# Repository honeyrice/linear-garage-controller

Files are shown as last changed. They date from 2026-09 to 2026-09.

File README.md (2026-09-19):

# Linear Garage Controller

[English](#english) | [简体中文](#简体中文)

## English

ESP32 + ESPHome retrofit for a **Linear LDCO800** garage opener: encoder-based motion and estimated position, feedback-driven Open/Close control, Home Assistant integration, and Bluetooth Proxy.

**Completed: 2026-09-18.** The original opener, motor, remotes, wall button, and factory protections are retained. The module reads the factory encoder and simulates button presses through a relay. The ESP32 locally translates Open / Close intentions into button sequences driven by feedback.

### Project photos

| Opener model | Factory logic board |
|---|---|
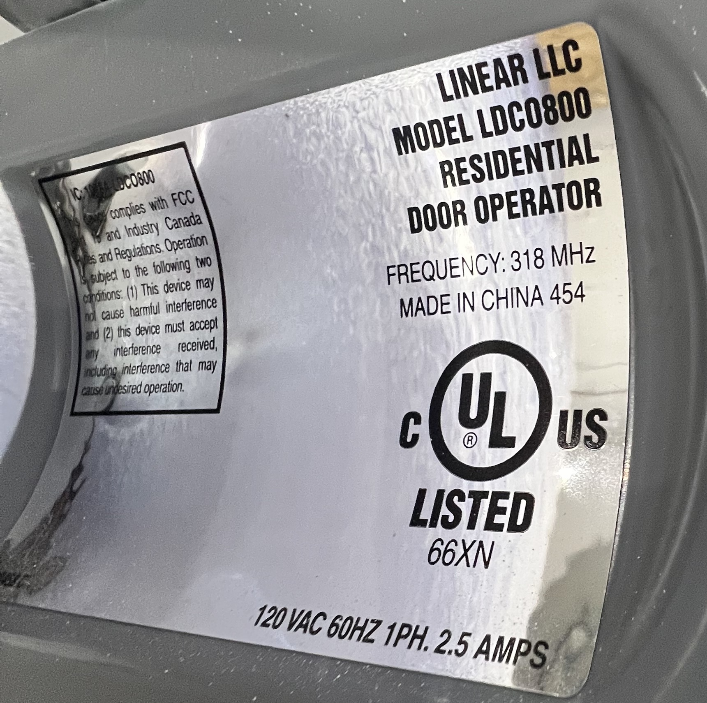
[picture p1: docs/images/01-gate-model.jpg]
Linear LDCO800 model nameplate
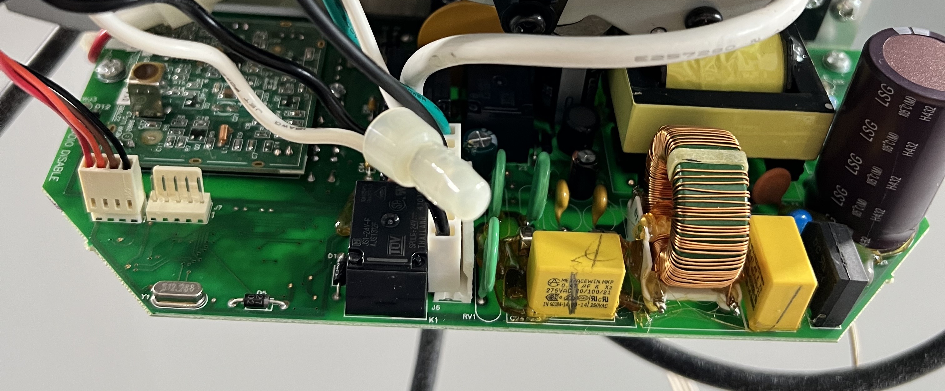
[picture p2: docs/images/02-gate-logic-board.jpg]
Linear LDCO800 factory logic board
|  |  |
| **Linear LDCO800** model nameplate and electrical specifications. | Original logic board and power section, retaining the encoder connection. |

| Components in the 3D-printed box | Finished module |
|---|---|
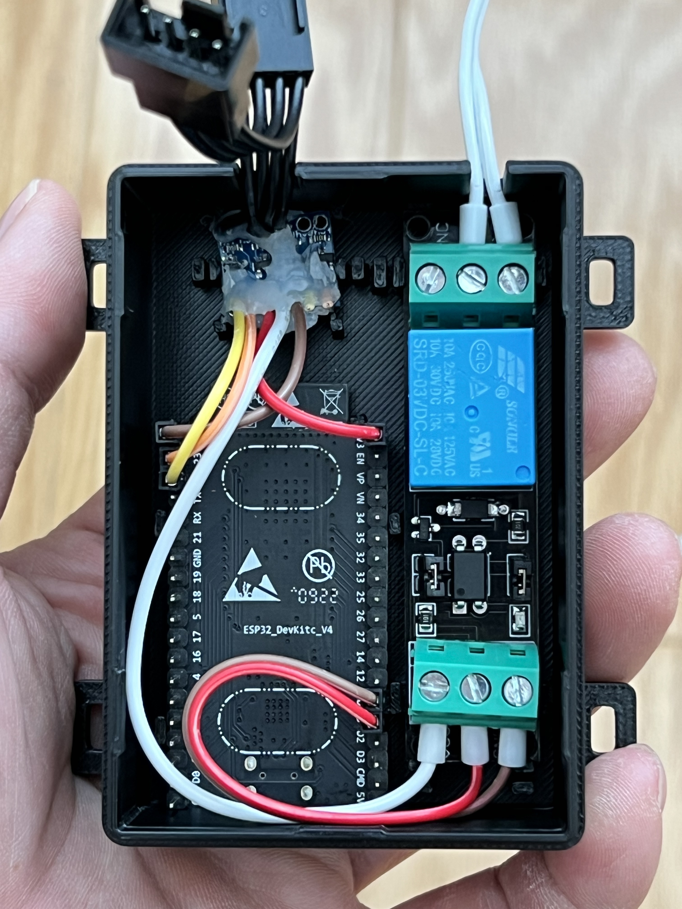
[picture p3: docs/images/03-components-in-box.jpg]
ESP32, level converter, and relay inside the printed enclosure
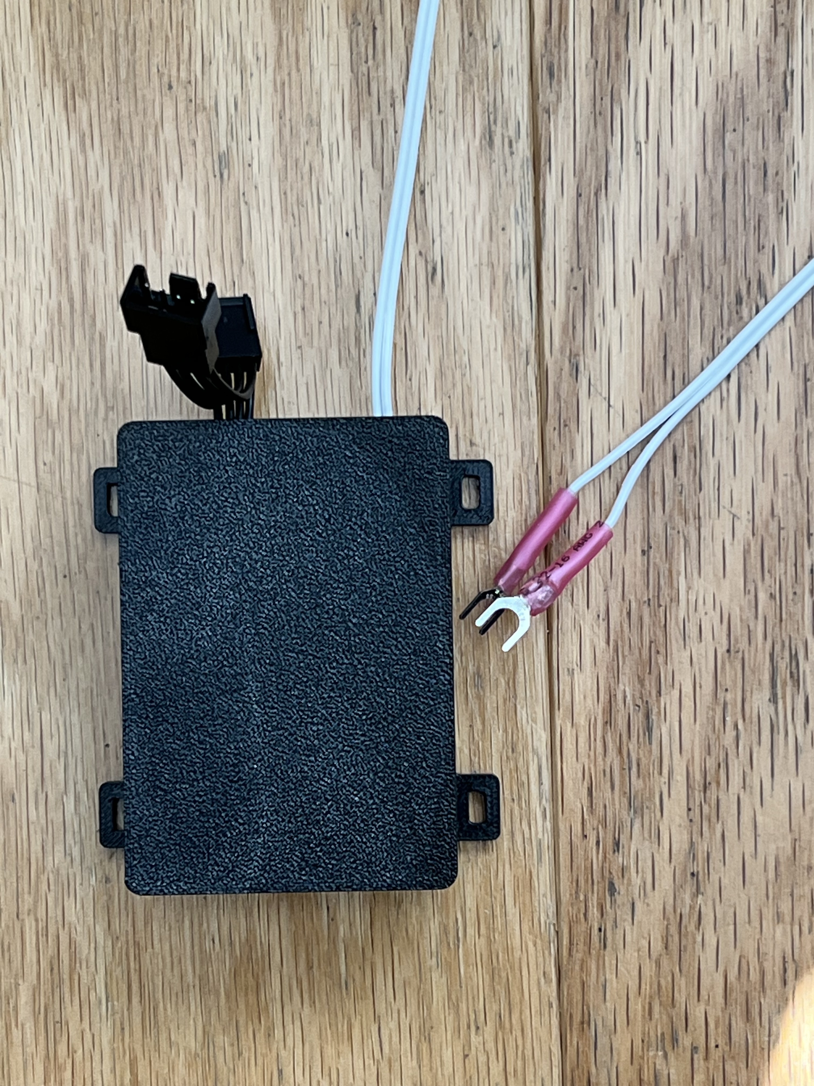
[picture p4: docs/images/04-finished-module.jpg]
Closed controller module and external leads
|  |  |
| ESP32 + level converter + 3.3 V relay. | Encoder Y cable, dry-contact leads, and mounting ears. |

These are actual project photographs. The model and board photographs received ordinary cropping; the other two retain their original framing. Camera metadata was removed from all four. No AI redrawing, retouching, or added annotations were used.

### Features

- **Encoder feedback:** GPIO22/23 read the two encoder channels to detect opening / closing / stopped and estimate opening percentage.
- **Closed-position reference:** an independent fully closed contact sensor provides a reference through HA; a stable confirmation recalibrates zero.
- **Directional control:** Open Gate / Close Gate prioritize the latest target; Gate Button remains available for a raw single press.
- **Home Assistant:** a HA `cover`, last-known-state cache, motion-start counts, travel durations, and abnormal-duration notifications.
- **Apple Home:** export as a garage door through HA HomeKit Bridge.
- **Bluetooth Proxy:** advertisement forwarding and active BLE connections, with three connection slots by default.

### Documentation

| Document | Contents |
|---|---|
| [Wiring & BOM](docs/WIRING.md#english) | Encoder, converter, ESP32, and 3.3 V relay |
| [Control logic](docs/CONTROL.md#english) | Repeated requests, reversal, unknown position, and pulse limits |
| [Firmware](firmware/README.md#english) | Build, credentials, calibration, and first connection |
| [Home Assistant](home-assistant/README.md#english) | Cover, cache, statistics, notifications, and HomeKit |
| [Enclosure & STL](enclosure/README.md#english) | V0.27 base/lid STLs, dimensions, and mesh checks |
| [Tests](tests/README.md#english) | Standalone C++ simulations and Python template tests |
| [Project summary](docs/PROJECT.md#english) | Measurements, installation, and Bluetooth tradeoffs |

### Quick start

1. Read the wiring guide and verify your opener's terminals, voltages, wire order, and relay specifications.
2. Install `requirements.txt` in a Python environment and supply your own configuration using the [firmware guide](firmware/README.md#english).
3. During initial commissioning, leave relay COM/NO disconnected while checking encoder direction, the contact sensor, and relay pulses.
4. Add the ESPHome device to HA, verify entity IDs, and install the desired templates following the [HA guide](home-assistant/README.md#english).
5. Connect the factory PUSHBUTTON / COMMON terminals after physical validation.

Run software-only checks, which do not connect to HA or actuate the door:

```sh
python tests/run_tests.py
```

### Scope and limitations

This documents a retrofit for one LDCO800, not a universal plug-and-play controller. The `1049` full-travel count and count direction were measured on this unit and must be calibrated for your installation. `open_estimated` means fully open as estimated from counts, without an independent fully open limit sensor. Unknown position after reboot is intentional; a historical cache does not replace current feedback.

When direction is unknown, a directional request may start with one probe and briefly move the opposite way. HA Stop is not an immediate emergency stop. Retain the factory beam sensor, obstacle reversal, and mechanical limits. Disconnect opener power before internal wiring. Relay contacts connect only to the low-voltage button terminals and **do not switch 120 V power**.

This is a separate, sanitized publication using generic node names and entity IDs. It excludes household credentials, network addresses, device MAC addresses/serial numbers, original operational logs, and flash binaries. When upgrading an existing installation, retain your node and entity identities rather than overwriting them with the example names.

See [NOTICE.md](NOTICE.md#english) for licensing and third-party provenance.

---

## 简体中文

这是基于 **Linear LDCO800** 的 ESP32 + ESPHome 改造项目：通过编码器识别运动方向、估算开度，以反馈驱动开关门控制，并集成 Home Assistant 与 Bluetooth Proxy。

**项目完成：2026-09-18。** 保留原开门器、电机、遥控器、墙壁按钮和原厂保护功能。读取原厂编码器，通过继电器模拟按钮，在 ESP32 本地把 Open / Close 意图转换为有反馈的按钮序列。

### 实物照片

| 开门器型号 | 原厂主板 |
|---|---|
| Linear LDCO800 型号铭牌 | Linear LDCO800 原厂主板 |
| **Linear LDCO800** 型号铭牌与电气规格。 | 原厂主板与电源区域，保留编码器接口。 |

| 打印盒内组件 | 合盖成品 |
|---|---|
| 打印盒内的 ESP32、电平转换板和继电器 | 合盖后的控制模块与引出线 |
| ESP32、电平转换板与 3.3 V 继电器。 | 编码器 Y 线、按钮干接点引线与固定耳。 |

以上为项目实物照片。型号与主板照片仅做普通裁剪，另外两张保留原画面；四张均去除相机元数据，没有 AI 重绘、修饰或添加标注。

### 功能

- **编码器反馈**：GPIO22/23 读取两路编码器信号，识别 opening / closing / stopped，估算开度。
- **全关参考**：独立全关门磁经 HA 提供参考，稳定确认后校准零点。
- **定向控制**：Open Gate / Close Gate 支持最新目标优先；保留 Gate Button 原始单次按键。
- **Home Assistant**：HA `cover`、最后已知状态缓存、运动起步次数、行程耗时及异常提醒。
- **Apple Home**：可经 HA HomeKit Bridge 暴露为车库门。
- **Bluetooth Proxy**：支持广播转发与主动 BLE 连接；默认三个连接名额。

### 资料导航

| 资料 | 内容 |
|---|---|
| [接线与物料](docs/WIRING.md#简体中文) | 编码器、转换板、ESP32、3.3 V 继电器 |
| [控制逻辑](docs/CONTROL.md#简体中文) | 重复请求、换向、未知位置、脉冲限制 |
| [固件](firmware/README.md#简体中文) | 构建、凭据、标定与首次接入 |
| [Home Assistant](home-assistant/README.md#简体中文) | Cover、缓存、统计、通知与 HomeKit |
| [外壳模型](enclosure/README.md#简体中文) | V0.27 底壳 / 上盖 STL、尺寸与网格核验 |
| [测试](tests/README.md#简体中文) | 独立 C++ 模拟与 Python 模板测试 |
| [项目总结](docs/PROJECT.md#简体中文) | 实测、安装与蓝牙取舍 |

### 快速开始

1. 阅读接线说明，核对自己开门器的端子、电压、线序及继电器规格。
2. 在 Python 环境安装 `requirements.txt`，按 [固件说明](firmware/README.md#简体中文) 填入自己的配置。
3. 初次调试先断开继电器 COM/NO 控制线，确认编码器方向、门磁与继电器脉冲。
4. 将 ESPHome 设备加入 HA，按 [HA 说明](home-assistant/README.md#简体中文) 核对实体 ID 并安装所需模板。
5. 完成现场验证后，再接入原厂 PUSHBUTTON / COMMON。

运行纯软件检查（不会连接 HA 或触发门）：

```sh
python tests/run_tests.py
```

### 适用范围

这是针对一台 LDCO800 的改造记录，不是所有开门器的通用即插即用方案。`1049` 全行程计数和计数方向来自本机实测，必须按自己的安装校准。`open_estimated` 表示计数估算的全开，没有独立全开限位。重启后位置未知是有意设计，历史缓存不替代当前反馈。

未知方向时，定向请求可先试探一次，因此可能短暂反向；HA Stop 也不是即时急停。原机的光束、遇阻反转与机械限位必须保留。进行机内接线前断开开门器电源；继电器触点仅连接低压按钮端子，**不切换 120 V 电源**。

这是经过私人信息清理的独立发布版：使用通用节点名和实体 ID，未包含家中凭据、网络地址、设备 MAC/序列号、原始运行日志或烧录二进制。已有安装升级时应保留自己的节点和实体身份，不要直接用示例改名覆盖。

许可及第三方来源见 [NOTICE.md](NOTICE.md#简体中文)。

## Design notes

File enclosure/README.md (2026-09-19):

# Enclosure & STL

[English](#english) | [简体中文](#简体中文)

## English

The latest CAD archive is V0.27. The main body measures approximately **82.22 × 57.5 × 32 mm**, excluding four external mounting ears. It houses three circuit boards, with connections for USB, a four-wire encoder branch, and two dry-contact leads.

See [dimensions.json](dimensions.json) for the full dimensional record. Values come from measurements and engineering envelopes for this unit; different development boards, headers, relays, and printing tolerances require checking. This file records dimensions and is not standalone CAD source that can generate the model.

The V0.27 control-wire opening is 4.23 × 2.23 mm, with its center 14.35 mm above the enclosure's external bottom surface. Use the complete base and matching lid together; do not freely mix older lids with this base.

Some lid-to-base snap geometry was adapted from external reference models. This directory provides the final V0.27 base and lid STLs. Original reference models and build scripts that depend on them are not included.

The author confirmed final printing, assembly, and installation inside the opener. Photographs cannot uniquely identify the printed STL revision. V0.27 is the latest CAD record; installation photographs are not exact revision identification.

### STL downloads

- [V0.27 complete base](stl/garage-v0.27-base.stl)
- [V0.27 matching lid](stl/garage-v0.27-lid.stl)
- [SHA-256 checksums](stl/SHA256SUMS)
- [Mesh validation results](mesh-validation.json)

Choose **Download raw file** on the GitHub file page. Both models use **millimeters (mm)**. STL does not store units, so import into the slicer as millimeters at 100% scale. The base includes external mounting ears, making its full bounding width about 73.9 mm; the 57.5 mm dimension above is the body width without ears.

Both STLs are byte-for-byte identical to the local V0.27 archive and have watertight meshes, consistent winding, and a single connected component. Publication only rechecked existing meshes; it did not include new slicing or physical fit testing.

---

## 简体中文

最新 CAD 档案为 V0.27，主体外形约 **82.22 × 57.5 × 32 mm**，不含四个外置固定耳。布置三块电路板，外接 USB、四芯编码器支路、两芯干接点线。

完整尺寸参数见 [dimensions.json](dimensions.json)。参数来自本机实测及工程包络；不同开发板、排针、继电器和打印公差须重新核对。该文件是尺寸记录，不是独立可生成模型的 CAD 源码。

V0.27 控制线孔为 4.23 × 2.23 mm，中心距盒子外底面 14.35 mm。完整底壳和上盖必须配套，旧上盖不能随意混搭。

外壳的部分盒盖扣合几何参考了外部模型。本目录提供最终 V0.27 底壳与上盖 STL；原始参考模型及依赖它们的构建脚本未包含。

项目最终打印、装配与机内安装已由作者确认；照片无法唯一识别打印 STL 的修订号。V0.27 是最新 CAD 记录，不把安装照片当作精确版本鉴定。

### STL 下载

- [V0.27 完整底壳](stl/garage-v0.27-base.stl)
- [V0.27 配套上盖](stl/garage-v0.27-lid.stl)
- [SHA-256 校验值](stl/SHA256SUMS)
- [本次网格核验](mesh-validation.json)

在 GitHub 文件页选择 **Download raw file** 下载。两个模型均使用 **毫米（mm）**；STL 本身不保存单位，导入切片软件时按毫米、100% 比例解释。底壳包含外置固定耳，完整包络宽度约 73.9 mm，正文 57.5 mm 为不含固定耳的主体宽度。

两份 STL 与本地 V0.27 档案逐字节一致，均为闭合网格、法线绕向一致、单个连通件。此次仅发布已有模型并重验网格，没有重新切片或进行新的实物试装。

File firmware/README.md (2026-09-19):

# ESPHome firmware

[English](#english) | [简体中文](#简体中文)

## English

Version used: ESPHome 2026.8.2, ESP-IDF framework, ESP32 with 4 MB flash. The publication retains the actual control algorithms and normalizes example names to `linear-garage-controller` / Linear Garage Controller, Gate State, Open Gate, Close Gate, and Controller Online.

### Configuration

From the repository root, install dependencies in your chosen Python environment:

```sh
python -m pip install -r requirements.txt
```

`ha-wifi.yaml` reads credentials from environment variables. Set `LINEAR_WIFI_SSID`, `LINEAR_WIFI_PASSWORD`, `LINEAR_API_KEY`, and `LINEAR_OTA_PASSWORD`. Do not commit their actual values to Git.

The API key is a Base64-encoded random 32-byte value. Generate credentials locally:

```sh
python -c 'import secrets; print(secrets.token_urlsafe(24))' # Suitable for an OTA password
python -c 'import secrets,base64; print(base64.b64encode(secrets.token_bytes(32)).decode())'
```

Example variable names are in [`.env.example`](../.env.example). ESPHome does not automatically load `.env`; export the variables through your shell or secret-management tool.

Set `closed_contact_entity` in `ha-wifi.yaml` to your contact sensor entity. Ensure **off = fully closed, on = not fully closed**. Normalize a different polarity in HA first. Without this valid reference, the device cannot establish absolute position after restarting.

`FULL_TRAVEL = 1049` and `positive = -raw` in `position_tracker.h` are calibrations for this installation. Initially verify full travel and sign using read-only observation, then adjust them to your measurements. They are not universal LDCO800 parameters. GPIO22/23 and GPIO13 are configured in `position.yaml` / `relay.yaml`.

### Validation and flashing

```sh
esphome config firmware/ha-wifi.yaml
esphome compile firmware/ha-wifi.yaml
```

After compilation, flash through the appropriate USB port for the board. The test machine defaults to **115200 baud**; avoid automatically trying 460800/921600. Stop serial monitoring before flashing. When using esptool, explicitly pass `--baud 115200`. Use image paths and offsets from the current ESPHome build rather than copying offsets from another board type.

Generated binaries contain your network/API/OTA credentials and must not be uploaded to a public repository or release.

### Software components

- `position_tracker.h`: counts, direction, zero reference, opening percentage, and closed-reference validity.
- `gate_controller.h`: directional button state machine with feedback.
- `position.yaml` / `relay.yaml`: ESPHome inputs, outputs, and state publication.
- `bluetooth.yaml`: full Bluetooth Proxy. If unnecessary, remove its include from the main configuration and rebuild.
- `memory.yaml`: heap-memory diagnostics.

Wi-Fi/API `reboot_timeout: 0s` prevents reboots caused solely by network disconnection. Continuous local counting and the control state machine do not require a network round trip for each step, but remote request delivery, the contact-sensor reference, and HA display still depend on the network.

---

## 简体中文

已使用版本：ESPHome 2026.8.2，ESP-IDF 框架，ESP32 4 MB。发布包保留实际控制算法，统一了示例名称：`linear-garage-controller` / Linear Garage Controller、Gate State、Open Gate、Close Gate、Controller Online。

### 配置

在本仓库根目录、所用 Python 环境中安装：

```sh
python -m pip install -r requirements.txt
```

`ha-wifi.yaml` 通过环境变量读取凭据。设置 `LINEAR_WIFI_SSID`、`LINEAR_WIFI_PASSWORD`、`LINEAR_API_KEY` 和 `LINEAR_OTA_PASSWORD`；不要把实际值提交到 Git。

API 密钥为 32 字节随机值的 Base64 编码，可本地生成：

```sh
python -c 'import secrets; print(secrets.token_urlsafe(24))' # 可用作 OTA 密码
python -c 'import secrets,base64; print(base64.b64encode(secrets.token_bytes(32)).decode())'
```

示例变量名见 [`.env.example`](../.env.example)。`.env` 不会被 ESPHome 自动加载，需要通过自己的 shell 或秘密管理工具导出变量。

修改 `ha-wifi.yaml` 的 `closed_contact_entity` 为自己的门磁实体，确保 **off = 完全关闭，on = 未完全关闭**。不同极性先在 HA 规范化。没有这个有效参考，设备重启后不能确定绝对开度。

`position_tracker.h` 的 `FULL_TRAVEL = 1049` 和 `positive = -raw` 是本机标定。首次以只读方式核对完整行程和正负，再按自己的测量调整；这里不是所有 LDCO800 都适用的固定参数。GPIO22/23 和 GPIO13 在 `position.yaml` / `relay.yaml` 设置。

### 校验和烧录

```sh
esphome config firmware/ha-wifi.yaml
esphome compile firmware/ha-wifi.yaml
```

编译完成后使用适合本板的 USB 端口烧录。测试机器默认 **115200 baud**，避免自动尝试 460800/921600；停止串口监视后再刷写。使用 esptool 时明确指定 `--baud 115200`，镜像路径/偏移以 ESPHome 本次生成结果为准，不能盲套其他板型。

生成二进制包含自己的网络/API/OTA 凭据，不能上传公开仓库或 release。

### 软件组成

- `position_tracker.h`：计数、方向、零点、开度、关闭参考有效性。
- `gate_controller.h`：带反馈的定向按钮状态机。
- `position.yaml` / `relay.yaml`：ESPHome 输入、输出和状态发布。
- `bluetooth.yaml`：完整 Bluetooth Proxy；如不需要可移除主配置中的这一项 include 并重编译。
- `memory.yaml`：堆内存诊断。

Wi-Fi/API 的 `reboot_timeout: 0s` 避免单纯断网重启。连续本地计数与控制状态机不依赖每一步网络往返，但远程请求送达、门磁参考及 HA 显示仍依赖网络。

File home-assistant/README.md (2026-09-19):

# Home Assistant

[English](#english) | [简体中文](#简体中文)

## English

These are portable examples. Check your own entity IDs first, and replace them consistently across this directory's YAML, Jinja, and generator scripts. Changing only one file can leave inconsistent statistics or test references.

### Entity mapping

| Example ID | Source |
|---|---|
| `sensor.linear_garage_controller_gate_state` | ESPHome Gate State |
| `sensor.linear_garage_controller_motion` | ESPHome Motion |
| `sensor.linear_garage_controller_opening` | ESPHome Opening |
| `binary_sensor.linear_garage_controller_controller_online` | ESPHome Controller Online |
| `button.linear_garage_controller_open_gate` | Open Gate |
| `button.linear_garage_controller_close_gate` | Close Gate |
| `button.linear_garage_controller_gate_button` | Gate Button |
| `binary_sensor.garage_closed_contact` | Independent contact sensor; off = fully closed |
| `notify.mobile_app_your_phone` | Your phone notification action |

HA may generate different IDs; use Developer Tools → States as the source of truth. After adding the device through the ESPHome integration, allow its required HA state subscriptions and confirm that the closed reference is available.

### Installing templates

Place these three files in HA's `templates/` directory:

- `garage_gate_controller.yaml`
- `linear_garage_cache.yaml`
- `linear_garage_statistics.yaml`

For a directory-merge setup, use this in `configuration.yaml`:

```yaml
template: !include_dir_merge_list templates/
homeassistant:
  packages: !include_dir_named packages/
```

Merge into existing `template` or `homeassistant` configuration without duplicating top-level keys. Place `linear_garage_statistics_package.yaml` in `packages/` and change its notification action first. Check the configuration, then reload templates and automations, or reload according to your existing include structure.

If `cover.garage_gate_controller` already exists, replace the original cover definition while retaining its unique_id and entity ID. **Do not load both definitions simultaneously.** A new installation can use the example IDs. Keeping the same cover identity preserves references from existing automations, dashboards, and HomeKit.

The cover's Open/Close actions call the local directional buttons. Stop sends a raw button press only when motion is opening/closing. The cover is unavailable offline. Arbitrary percentage positioning is not implemented: displaying an opening percentage does not imply support for `set_cover_position`.

### Cache and statistics

Last Known Gate State stores only the last valid state, opening percentage, and recording time. Live unknown/unavailable states do not overwrite it. The cache may be stale and must not be treated as current safety information or used directly for directional control.

Statistics include daily/lifetime opening and closing motion-start counts, the latest full-travel duration, learned duration baselines for each direction, and time spent not fully closed. Counts reflect observed motion, including factory-button operations and restarts midway; they are not command counts or complete round-trip counts.

Only complete trips train the baseline. Trips interrupted by stops, reversals, disconnection, or reboot are excluded from normal samples. Slow-travel alerts become active after at least five samples per direction and use the median of the last ten normal complete trips. A trip must exceed the baseline by both 30% and two seconds to trigger an alert. Alerts notify only; they do not close the door. Network and stop-detection delays are included in the measurement, so an alert alone does not diagnose a mechanical fault.

Generate the statistics YAML with:

```sh
python home-assistant/build_statistics.py
```

`gate_left_open_package.yaml` is an optional example that notifies after the door remains open for ten minutes. Set your notification action before placing it in packages. Reuse an existing equivalent automation to avoid duplicate alerts. HA `for` timers reset on restart or automation reload.

### HomeKit Bridge

Add **`cover.garage_gate_controller`** to the included entities of your existing HomeKit Bridge. Do not represent the raw button as a light. If the same cover was already exported and its identity is unchanged, replacing the backend usually does not require rebuilding the bridge. Still confirm state and operation in the Apple Home client.

Project records verify HA-side bridge inclusion and the existing accessory identity; HA screenshots are not Apple Home client acceptance evidence. Follow HomeKit's operating requirements for locks and garage doors.

---

## 简体中文

这些是可移植示例，需要先核对自己的实体 ID。适配时在此目录的 YAML、Jinja 和生成脚本中统一替换；只改一个文件会使统计或测试引用不一致。

### 实体映射

| 示例 ID | 来源 |
|---|---|
| `sensor.linear_garage_controller_gate_state` | ESPHome Gate State |
| `sensor.linear_garage_controller_motion` | ESPHome Motion |
| `sensor.linear_garage_controller_opening` | ESPHome Opening |
| `binary_sensor.linear_garage_controller_controller_online` | ESPHome Controller Online |
| `button.linear_garage_controller_open_gate` | Open Gate |
| `button.linear_garage_controller_close_gate` | Close Gate |
| `button.linear_garage_controller_gate_button` | Gate Button |
| `binary_sensor.garage_closed_contact` | 独立门磁，off=全关 |
| `notify.mobile_app_your_phone` | 自己的手机通知 action |

HA 实际自动生成的 ID 可能不同，以“开发者工具 → 状态”为准。用 ESPHome 集成加入设备后，允许该设备执行所需 HA 状态订阅，并确认全关参考可用。

### 安装模板

将以下三个文件放入 HA 的 `templates/` 目录：

- `garage_gate_controller.yaml`
- `linear_garage_cache.yaml`
- `linear_garage_statistics.yaml`

如使用目录合并方式，`configuration.yaml` 中为：

```yaml
template: !include_dir_merge_list templates/
homeassistant:
  packages: !include_dir_named packages/
```

如已有 `template` 或 `homeassistant` 配置，合并进去，不要重复顶层键。把 `linear_garage_statistics_package.yaml` 放入 `packages/`，并先修改通知 action。检查配置后重载模板和自动化，或按自己已有包含结构重载。

如果已经存在 `cover.garage_gate_controller`，替换原 cover 的定义，保留原来的 unique_id 与实体 ID；**不要同时加载两个定义**。新安装可使用示例中的 ID。这样现有自动化、仪表盘和 HomeKit 可继续引用同一 cover。

Cover 的 Open/Close 调用本地定向按钮；Stop 仅在 motion 为 opening/closing 时发原始按键。离线时 cover 不可用。没有实现任意百分比位置控制，显示开度不等于支持 `set_cover_position`。

### 缓存与统计

Last Known Gate State 只保存上一次有效状态、开度及记录时间；实时 unknown/unavailable 不覆盖缓存。缓存可能过时，不能据此判断当前安全状况或直接用于定向控制。

统计包含今日/累计开关运动起步次数、最近完整行程耗时、按方向学习的耗时基准、门保持未关闭的时长。计数依据观察到的运动，包括原厂按钮和中途重新启动；不是命令次数或完整往返次数。

完整行程才训练基准；中停、反转、离线和重启中断的行程不纳入正常样本。每个方向至少五次样本后启用慢行程提醒，取最近十次正常完整行程的中位数；同时超过基准 30% 且多出两秒才触发。提醒只通知，不自动关门；网络与停止检测延迟也计入测量，不能单凭提醒诊断机械故障。

生成统计 YAML：

```sh
python home-assistant/build_statistics.py
```

开门超过十分钟通知的可选示例为 `gate_left_open_package.yaml`，放入 packages 前先设置自己的通知 action。已有同类提醒时复用现有自动化，避免重复提醒。HA 的 `for` 计时会在重启/自动化重载时重置。

### HomeKit Bridge

在现有 HomeKit Bridge 的包含实体列表中加入 **`cover.garage_gate_controller`**。不要把原始按钮模拟成灯。若同一 cover 原本已导出且身份未变，后端替换通常无需重建桥接；仍需在 Apple Home 客户端实际确认状态和操作。

项目记录验证了 HA 侧 bridge 包含与原有 accessory 身份，未把 HA 截图当成 Apple Home 客户端验收。使用 HomeKit 时遵循其针对门锁/车库门的操作要求。

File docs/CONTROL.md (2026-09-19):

# Directional control

[English](#english) | [简体中文](#简体中文)

## English

Open Gate and Close Gate are target requests; Gate Button is a raw single press. The factory button stops a moving door and usually reverses direction on the next activation after stopping, so the same target can require different numbers of pulses depending on the current state.

| State / request | Behavior |
|---|---|
| Already at the target endpoint or moving toward it | Do not add a pulse |
| Moving in the opposite direction | Stop, confirm that motion has stopped, then restart |
| Stopped midway; previous direction opposite to target | Usually one pulse |
| Stopped midway; previous direction same as target | Usually reverse → stop → desired direction, three pulses |
| Close immediately after Open | Retain the latest target, wait for the current pulse/cooldown, then reverse using feedback |
| Absolute position unknown, actual direction known | Use live motion direction |
| Direction also unknown | Probe once, observe feedback, then adjust; a brief movement in the opposite direction is possible |
| Closed reference still settling | Defer action to avoid treating a just-closed door as stopped midway |
| Count out of range | Report a fault instead of using ordinary unknown-position probing |

Each pulse lasts 500 ms, followed by a 1500 ms cooldown. No new encoder edge for 1500 ms means stopped. If there have already been no edges for the last 250 ms, defer a stop pulse based on stale motion status. An active sequence allows at most 6 pulses over 20 seconds, with up to 5 seconds of feedback waiting per step. Rapid changes of target do not extend the sequence's overall deadline.

Startup and reconnection do not trigger movement or restore an old target. Missing feedback does not cause unlimited retries. The sequence ends once the requested motion direction is confirmed: `opening_confirmed` does not mean fully open. A later factory obstacle reversal does not make this module repeatedly attempt to close the door.

Gate Button cancels the directional target and queues one raw press, subject to the pulse cooldown. HA Stop sends a raw press only when HA considers the door to be moving. Network delay, stop detection, and endpoint races can still affect the result; it is not an immediate emergency stop.

State values are `closed`, `opening`, `closing`, `stopped`, `unknown`, and `open_estimated`. Fully closed requires the contact sensor plus a 2.5-second settling period. Fully open is estimated at 99.5% of the calibrated full-travel count.

Offline simulation cannot cover every mechanical response. The current inputs cannot reliably distinguish a frozen encoder from a stationary door, and do not replace the factory protections.

---

## 简体中文

Open Gate / Close Gate 是目标请求；Gate Button 是原始单次按键。原生按钮在运动中停车，停止后通常反向，因此同一目标在不同状态下可能需要不同脉冲数。

| 状态 / 请求 | 行为 |
|---|---|
| 已到目标端点，或已向目标方向运动 | 不追加脉冲 |
| 正向相反方向运动 | 先停，确认停止后再启动 |
| 中途停止，上次方向与目标相反 | 通常一次脉冲 |
| 中途停止，上次方向与目标相同 | 通常反向 → 停止 → 目标方向，共三次 |
| Open 后立即 Close | 保存最新目标，等待当前脉冲/冷却并按反馈换向 |
| 绝对位置未知，实际方向已知 | 按实时方向处理 |
| 方向也未知 | 一次试探，观察反馈再调整，可能短暂反向 |
| 关闭参考正在稳定确认 | 暂缓，避免将刚到底误判成中途停止 |
| 计数越界故障 | 报错，不按一般未知位置试探 |

每个脉冲 500 ms，冷却 1500 ms。无新边沿 1500 ms 判定停止；近期 250 ms 已无边沿时暂缓按旧运动状态发停车脉冲。单轮最多 6 个脉冲 / 20 秒，每一步反馈等待最多 5 秒，快速改目标不延长该轮总时限。

启动、重连不自动移动或恢复旧目标；无反馈不无限重试。确认目标运动方向后结束序列，不能把 `opening_confirmed` 当成到达全开。后续原厂遇阻反向也不会触发本模块持续重新关门。

Gate Button 取消定向目标并排队一次原始按键，受脉冲冷却约束。HA Stop 仅在 HA 认为正在运动时发送原始按键；网络延迟、停止判定和端点竞争仍可能影响行为，它不是即时急停。

状态值：`closed`、`opening`、`closing`、`stopped`、`unknown`、`open_estimated`。全关依赖门磁和 2.5 秒稳定确认；全开为满行程计数 99.5% 阈值估算。

离线模拟不能涵盖全部机械响应。编码器冻结与真实静止仅靠当前输入无法完全区分，不能替代原厂保护。

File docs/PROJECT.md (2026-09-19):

# Project summary

[English](#english) | [简体中文](#简体中文)

## English

Final assembly, wiring, and installation inside the opener were completed on 2026-09-18. The project grew from sensing the garage door's state to providing explicit Open/Close control, HA integration, and a compact enclosure.

### Design evolution

The original Linear LDCO800 system is retained. A four-wire Y cable adds a parallel encoder branch, a level converter feeds the ESP32, and an independent contact sensor supplies the fully closed reference. A relay momentarily closes the factory button terminals. The ESP32 has its own USB supply and executes the control algorithm locally.

The first actual closed → open → closed run produced raw counts of `0 → -1049 → 0`. Software normalizes opening to positive counts and uses the closed contact to calibrate zero. The 1049-count travel is an initial measurement from this particular installation, not a substitute for calibrating another unit.

A single button must be interpreted according to state: it stops motion and usually reverses direction after a stop. The controller therefore gives priority to the latest target, leaves repeated same-direction requests uninterrupted, queues rapid reversal requests, and probes once when direction is unknown. Regression tests cover cooldowns, endpoints, cancellation, and unknown-position cases.

The enclosure went through revisions to board length, header clearance, clips, wire exits, and insertion direction. The latest CAD revision is V0.27. Final physical assembly and installation are confirmed, but the photographs cannot uniquely identify the printed STL revision. Dimensions and model publication details are in the enclosure directory.

### Validation evidence

- The Y cable passed pin-to-pin continuity checks and retained normal factory operation.
- An actual round trip returned the count to zero; the user also observed HA feedback over multiple opening/closing cycles.
- With relay COM/NO disconnected, one energize/release cycle and a subsequent released state were confirmed.
- Final photographs confirm button-terminal wiring and installation inside the opener. HA screenshots record opening / 30%, and closed / stopped / 0%, online, and calibrated states.
- Software validation includes 63 directional-control simulation scenarios and replay of 301 actual count samples, plus 19 statistics tests and 8 cover tests.

Passing simulation does not mean every mechanical corner case has been physically tested. Fully open remains an estimate, while long-term Bluetooth coexistence and notification behavior require continued operational observation.

### Bluetooth Proxy tradeoff

Bluetooth enabled and disabled configurations each received 60 read-only API information queries, plus warmup queries. The timeout was 5 seconds and the query interval was at least 1 second.

| Metric | Bluetooth enabled | Bluetooth disabled |
|---|---:|---:|
| Success / failure or timeout | 60 / 0 | 60 / 0 |
| Median | 36.97 ms | 97.72 ms |
| Maximum | 1861.15 ms | 174.76 ms |

With Bluetooth enabled, the tail reached about 1.86 seconds, but the median was lower. One sequential A/B run cannot establish causation. These were not door-command latency measurements and do not prove zero packet loss at the transport level. The final choice was to retain the full Bluetooth Proxy functionality and avoid a separate proxy board.

### HA integration

A garage cover provides Open, Close, limited Stop, and position display, replacing the previous light-style button backend. The last-valid-state cache is separate from live state; statistics and alerts only observe and notify. Existing dashboards, automations, and HomeKit retain the cover identity. The publication uses generic entity examples; private configuration and original field logs remain local.

---

## 简体中文

2026-09-18 完成最终组装、接线和原机内部安装。目标从“知道车库门开关状态”扩展为明确的 Open/Close 控制、HA 集成与紧凑外壳。

### 方案演进

保留 Linear LDCO800 原系统，通过四芯 Y 线引出编码器支路。电平板将信号送给 ESP32，独立门磁提供全关参考；继电器短时闭合原厂按钮端子。ESP32 USB 单独供电，控制算法在本地执行。

真实首次全关 → 全开 → 全关读数为 `0 → -1049 → 0`。软件将开门方向统一成正值，并使用全关门磁校准零点。行程 1049 是本台设备的初始测量，不能代替另一台机器的标定。

单按钮操作必须按状态解释：运动时停车，停止后一般反向。因此实现最新目标优先、重复同向请求不打断、快速反向请求排队，以及未知方向时一次试探。回归测试覆盖冷却、端点、取消和未知位置场景。

外壳经历板长、排针高度、卡扣、导线出口和装入方向的多次修订；最新 CAD 为 V0.27。最终实物组装与安装已确认，照片不能唯一鉴定使用的 STL 修订号。发布的尺寸与模型许可状态见 enclosure 目录。

### 验证证据

- Y 线逐端连通与原厂功能验证通过。
- 真实往返计数回到零；用户多次开关时 HA 状态有反馈。
- 继电器 COM/NO 留空时，已确认一次吸合、释放并保持释放。
- 最终照片确认按钮端子接线与机内安装；HA 截图记录 opening / 30%，以及 closed / stopped / 0%、在线和校准完成。
- 软件验证包含 63 个定向控制模拟场景和 301 条实际计数回放；另有 19 个统计与 8 个 cover 测试。

模拟通过不代表每个机械边界场景都已现场实测。全开仍为估算，长期蓝牙共存及提醒效果仍依靠运行积累。

### Bluetooth Proxy 的取舍

对启用和关闭蓝牙各进行了 60 次只读 API 信息查询，另有预热，超时阈值为 5 秒，查询间隔至少 1 秒。

| 指标 | 蓝牙启用 | 蓝牙关闭 |
|---|---:|---:|
| 成功 / 失败或超时 | 60 / 0 | 60 / 0 |
| 中位数 | 36.97 ms | 97.72 ms |
| 最慢 | 1861.15 ms | 174.76 ms |

启用时有约 1.86 秒长尾，但中位数更低。一次顺序 A/B 不能确定因果；这不是开关门命令延迟测试，也不证明底层零丢包。最终选择保留完整 Bluetooth Proxy，以减少另一块独立代理板。

### HA 集成

统一使用 garage cover 提供开、关、受限 Stop 及开度显示，替换旧 light 形式的按钮后端。最后有效状态缓存与实时状态分开，统计和提醒只观察/通知。原有仪表盘、自动化及 HomeKit 保留 cover 身份。发布版使用通用实体示例，私人配置和现场原始日志留在本地。

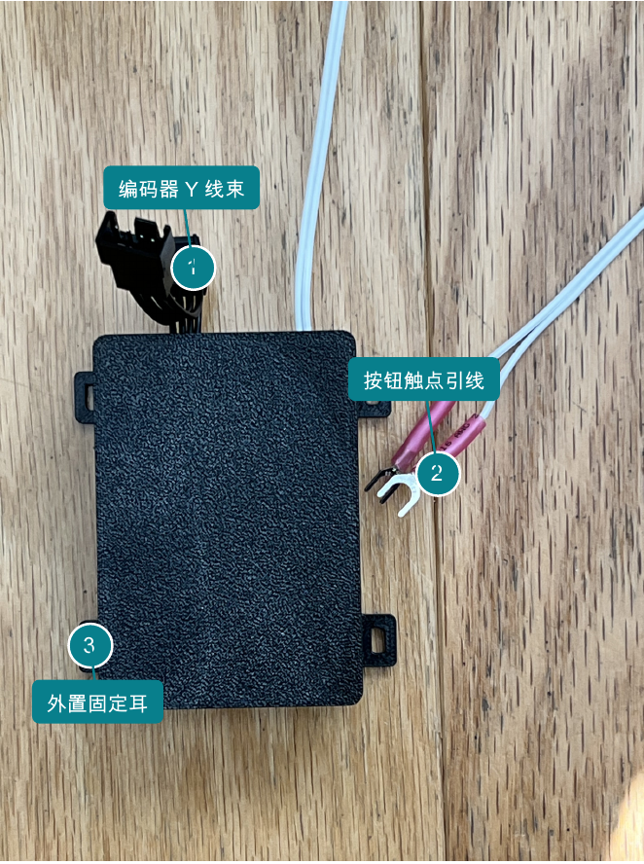
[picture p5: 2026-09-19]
docs/images/06-closed-enclosure.png

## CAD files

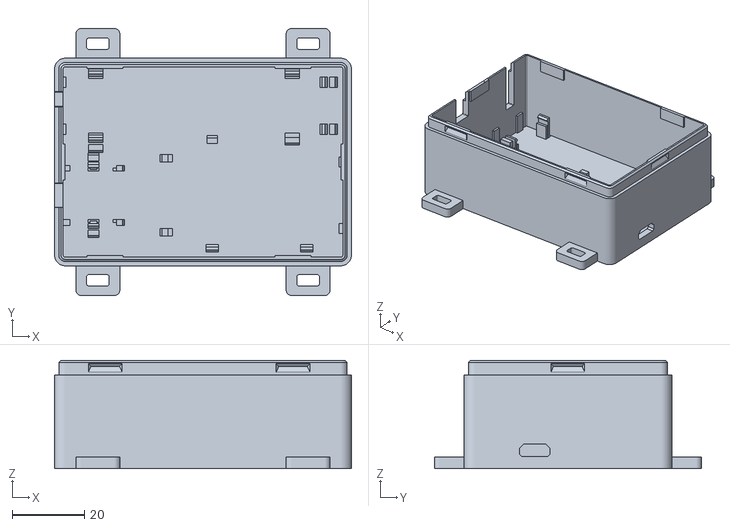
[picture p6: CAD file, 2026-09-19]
enclosure/stl/garage-v0.27-base.stl
82.2 x 73.9 x 30.0

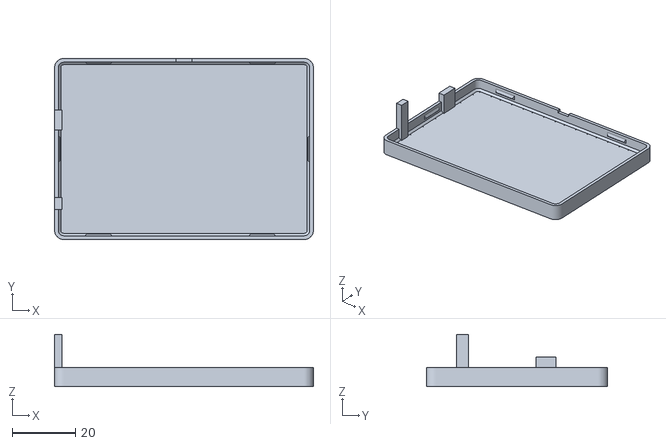
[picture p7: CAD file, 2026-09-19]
enclosure/stl/garage-v0.27-lid.stl
82.2 x 57.5 x 16.5

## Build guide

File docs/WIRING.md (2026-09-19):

# Wiring & BOM

[English](#english) | [简体中文](#简体中文)

## English

| Component | Configuration used in this project |
|---|---|
| Opener | Linear LDCO800 with its original dual-channel encoder |
| Controller | ESP32-WROOM-32E, 38-pin, 4 MB development board |
| Splitter | Four-wire, straight-through 4-pin Y splitter |
| Level converter | Four-channel bidirectional HV/LV module; two channels used |
| Relay | SRD-03VDC-SL-C module, 3 V coil, active-high input |
| Closed reference | Independent contact sensor; HA off = fully closed, on = not fully closed |
| Power | Separate USB supply for ESP32; 3V3 supplies converter LV and relay VCC |
| Wiring | Short internal 28 AWG Dupont leads and 22 AWG wire, securely fastened with strain relief |

Electrical wiring diagram, with Chinese labels

The diagram shows electrical connections, not the physical header order of arbitrary modules. Its labels are in Chinese; the table below gives the complete encoder connection mapping in English. Factory wire colors are records from this unit and must be verified by measurement before reuse.

| Factory connection | Level converter | ESP32 |
|---|---|---|
| E4 red, measured about 4.94 V | HV | Do not connect to ESP32 3V3 / USB 5V |
| E3 orange, encoder channel one | HV1 → LV1 | GPIO22 |
| E2 brown, encoder channel two | HV2 → LV2 | GPIO23 |
| E1 black, ground | GND | GND |
| Low-voltage reference | LV | 3V3 |

The original encoder-to-mainboard path remains straight through; the added branch reads the signals in parallel. The factory approximately 5 V supply is only the HV reference, not the ESP32 power source. A shared ground does not mean this converter provides electrical isolation.

### Relay

- VCC → ESP32 3V3; GND → ESP32 GND; IN → GPIO13.
- COM / NO → factory COMMON / PUSHBUTTON terminals. This contact pair has no polarity requirement.
- Leave NC unused. Do not connect to the BEAM safety-sensor terminals or inject ESP32 supply voltage into the button terminals.
- This board uses a 3 V coil module. If substituting a 5 V module, recheck its supply requirements, trigger threshold, and ESP32 compatibility.

First leave COM/NO disconnected and observe one energize action followed by release about 0.5 seconds later. Also verify that power-up/reset does not cause an unintended activation. Unloaded relay operation and final installation have been confirmed for this project; firmware `ALWAYS_OFF` does not prove that every development board is free of output pulses during power-up transients.

Components installed in the enclosure

### Installation sequence

1. Disconnect power and check matching Y-cable pin continuity and absence of shorts.
2. Verify normal operation of the factory wiring before adding the converter and ESP32.
3. In a controlled on-site test, confirm opening/closing direction, full-travel count, and closed reference.
4. After confirming relay pulses, connect the low-voltage button terminals. Finish insulation, fastening, and wire strain relief.
5. Close the enclosure after wiring and validation, maintaining appropriate separation from mains circuitry inside the opener.

---

## 简体中文

| 元件 | 本项目配置 |
|---|---|
| 开门器 | Linear LDCO800，原厂双路编码器 |
| 控制板 | ESP32-WROOM-32E，38-pin、4 MB 开发板 |
| 分线器 | 四线一一连通的 4-pin Y splitter |
| 电平转换 | 四通道 HV/LV 双向转换模块，使用两通道 |
| 继电器 | SRD-03VDC-SL-C 模块，3 V 线圈，高电平触发 |
| 全关参考 | 独立门磁，HA 中 off=全关，on=未全关 |
| 供电 | 独立 USB 给 ESP32；3V3 给电平板 LV 和继电器 VCC |
| 连线 | 盒内短距 28 AWG 杜邦线与 22 AWG 接线，需可靠固定与应力释放 |

电气接线图

图表示电气网络，不能当作任意模块的实际排针顺序。原厂线色仅是本机记录；测量确认后才能套用。

| 原厂网络 | 电平板 | ESP32 |
|---|---|---|
| E4 红，实测约 4.94 V | HV | 不连接 ESP32 3V3 / USB 5V |
| E3 橙，编码器一路 | HV1 → LV1 | GPIO22 |
| E2 棕，编码器另一路 | HV2 → LV2 | GPIO23 |
| E1 黑，地 | GND | GND |
| 低压侧参考 | LV | 3V3 |

编码器和原厂主板之间保留直通路径；额外支路只是并接采集。原厂约 5 V 用于 HV 参考，不为 ESP32 供电。共地并不代表这块转换板提供电气隔离。

### 继电器

- VCC → ESP32 3V3；GND → ESP32 GND；IN → GPIO13。
- COM / NO → 原厂 COMMON / PUSHBUTTON 两个按钮端子；这对触点本身不要求极性。
- NC 不用；不接 BEAM 安全光束端子，也不向按钮端子注入 ESP32 电源。
- 本板供电规格为 3 V 线圈模块。若换成 5 V 模块，必须重新核对模块供电、触发门限和 ESP32 兼容性。

先在 COM/NO 留空时观察一次吸合、约 0.5 秒后释放，再验证上电/复位不误触发。本项目已确认空载吸合释放及最终装机，固件 `ALWAYS_OFF` 不等于证明任何开发板的上电瞬态均无脉冲。

最终内部组装

### 安装顺序

1. 断电，核对 Y 线各对应端子的连通与无短路。
2. 先验证原厂线路正常，再接转换板与 ESP32。
3. 在受控现场确认开关方向、满行程计数与关闭参考。
4. 确认继电器脉冲后连接低压按钮端子；整理绝缘、固定和线束应力释放。
5. 接线与验证完成后合盖，确保新增模块与机内市电部分保持合适隔离。

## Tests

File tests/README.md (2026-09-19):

# Offline tests

[English](#english) | [简体中文](#简体中文)

## English

After installing requirements.txt, run from the repository root:

```sh
python tests/run_tests.py
```

Requirements are a C++17 compiler, Python, Jinja2, and PyYAML. The script only creates temporary test executables; it does not access the network, serial ports, HA, or the relay.

- `gate_controller_v2_test.cpp` / `gate_control_sim.h`: a deterministic door model driven by the actual header-file algorithms, covering repeated targets, rapid reversal, endpoints, queuing, and error handling.
- `position_tracker_test.cpp`: startup, calibration, stale contact state, out-of-range counts, clock wraparound, and field-count replay.
- `field-counts.txt`: 301 COUNT values extracted from the first actual round-trip recording. Timestamps, boot information, and network information were removed. Tests replay the counts at 500 ms intervals and simulate contact-sensor events; this does not imply that the original log captured contact-event timing.
- `home-assistant/test_statistics.py`: 19 statistics scenarios.
- `home-assistant/test_cover_migration.py`: 8 cover state/routing scenarios.

Tests use this installation's 1049-count travel as a fixed fixture. If travel or control parameters change, update the model and replay expectations accordingly. Passing results are software evidence and do not replace actual door-motion tests, hardware-reset transient checks, printed-fit checks, or long-term stability validation.

On macOS, if Command Line Tools cannot find a standard header such as `cstdint`, first repair the developer-tool selection, or set this for the current run:

```sh
CPLUS_INCLUDE_PATH="$(xcrun --show-sdk-path)/usr/include/c++/v1" python tests/run_tests.py
```

---

## 简体中文

在仓库根目录安装 requirements.txt 后运行：

```sh
python tests/run_tests.py
```

需要 C++17 编译器、Python、Jinja2 和 PyYAML。脚本只创建临时测试可执行文件，不访问网络、串口、HA 或继电器。

- `gate_controller_v2_test.cpp` / `gate_control_sim.h`：实际头文件算法驱动的确定性门模型，覆盖重复目标、快速反向、端点、排队与错误处理。
- `position_tracker_test.cpp`：启动、校准、过期门磁、计数越界、时间回绕及现场计数回放。
- `field-counts.txt`：首次实际往返记录中提取的 301 个 COUNT 值。删除了时间、启动与网络信息。测试按 500 ms 采样间隔回放，并模拟门磁事件；不声称原日志同时记录了门磁时间。
- `home-assistant/test_statistics.py`：19 个统计场景。
- `home-assistant/test_cover_migration.py`：8 个 cover 状态/路由场景。

测试使用本机行程 1049 作为固定样例。修改行程或控制参数后需相应调整模型和回放预期。通过结果是软件证据，不能替代真实门动作、硬件复位瞬态、打印适配和长期稳定性验证。

macOS 若 Command Line Tools 报标准头文件（如 `cstdint`）找不到，可先修复开发工具选择，或为本次运行设置：

```sh
CPLUS_INCLUDE_PATH="$(xcrun --show-sdk-path)/usr/include/c++/v1" python tests/run_tests.py
```

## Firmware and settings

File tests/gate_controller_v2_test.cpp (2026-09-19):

#include "gate_control_sim.h"
bool ok(const Sim &s) { return std::string(s.control.status()).find("error_")!=0; }
void unknown(Sim &s,int pos,int last) {
  s.prepare(pos,last);
  s.tracker=PositionTracker{}; s.encoder_count=0;
  s.run(3000); s.origin=s.now;
  assert(!s.tracker.calibrated() && s.tracker.last_direction()==0);
}
int main() {
  std::cout << std::unitbuf;
  unsigned cases=0;
  for(int d:{-1,1}) for(uint32_t gap:{0U,50U,500U,1950U,2000U,2500U,5000U,22000U}) {
    Sim s; if(d==-1) s.prepare(1049,1);
    assert(s.request(d)); s.run(gap); assert(s.request(d)); s.run(25000);
    assert(s.rejected==0 && s.pulses.size()==1 && s.pos==(d==1?1049:0) && ok(s));
    s.summary(("same_target_"+std::to_string(d)+"_gap_"+std::to_string(gap)).c_str()); ++cases;
  }
  for(int d:{-1,1}) for(uint32_t gap:{0U,50U,100U,500U,1000U,1950U,2000U,2500U,5000U}) {
    Sim s; if(d==-1) s.prepare(1049,1);
    s.request(d); s.run(gap); assert(s.request(-d)); s.run(30000);
    assert(s.rejected==0 && s.pos==(d==1?0:1049) && ok(s));
    assert(s.pulses.size()==(gap==0?0U:3U));
    s.summary(("latest_target_"+std::to_string(-d)+"_gap_"+std::to_string(gap)).c_str()); ++cases;
  }
  for(int target:{-1,1}) for(int last:{-1,1}) {
    Sim s; s.prepare(500,last); s.request(target); s.run(10000);
    assert(s.pulses.size()==(target==last?3U:1U) && ok(s));
    assert(s.physical==target || s.pos==(target==1?1049:0));
    s.summary(("stopped_last_"+std::to_string(last)+"_target_"+std::to_string(target)).c_str()); ++cases;
  }
  for(int p:{20,100,990,1029}) {
    int target=p<500?1:-1;
    Sim s; s.prepare(p,target); s.request(target); s.run(10000);
    assert(s.physical==target && s.pulses.size()==2 && ok(s));
    s.summary(("endpoint_race_fixed_"+std::to_string(p)).c_str()); ++cases;
  }
  {
    Sim s; s.prepare(30,-1,-1); s.run(2000); assert(s.pos==0);
    s.request(-1); s.run(4000); assert(s.pulses.empty() && s.pos==0 && ok(s));
    s.summary("closed_settling_close_no_reopen"); ++cases;
  }
  for(uint32_t retarget:{500U,2500U,4200U}) {
    Sim s; s.prepare(500,1); s.request(1); s.run(retarget); s.request(-1); s.run(15000);
    assert(s.rejected==0 && s.pos==0 && ok(s));
    s.summary(("three_step_retarget_close_"+std::to_string(retarget)).c_str()); ++cases;
  }
  {
    Sim s; s.request(1); s.run(500); s.request(-1); s.run(500); s.request(1); s.run(25000);
    assert(s.pulses.size()==1 && s.pos==1049 && ok(s));
    s.summary("open_close_open_before_stop"); ++cases;
  }
  {
    Sim s; s.request(1); s.run(500); s.request(-1); s.run(2000); s.request(1); s.run(30000);
    // Reverse leg reaches closed endpoint before its planned stop: replan there.
    assert(s.pulses.size()==4 && s.pos==1049 && ok(s));
    s.summary("open_close_open_after_stop_issued"); ++cases;
  }
  {
    Sim s; s.prepare(500,1); s.request(1); s.run(500); s.raw(); s.run(6000);
    assert(s.pulses.size()==2 && s.physical==0 && !s.control.busy());
    s.summary("raw_press_queued_not_dropped"); ++cases;
  }
  {
    Sim s; s.request(1); s.run(5000); s.external_press(); s.run(500); s.request(1); s.run(9000);
    assert(s.pulses.size()==4 && s.physical==1 && ok(s));
    s.summary("external_stop_settling_resume"); ++cases;
  }
  for(int target:{-1,1}) for(int last:{-1,1}) {
    Sim s; unknown(s,500,last); s.allow_probe=true; s.request(target); s.run(10000);
    assert(s.pulses.size()==(target==last?3U:1U) && ok(s));
    assert(s.physical==target || s.pos==(target==1?1049:0));
    s.summary(("unknown_probe_last_"+std::to_string(last)+"_target_"+std::to_string(target)).c_str()); ++cases;
  }
  {
    Sim s; unknown(s,500,1); s.request(1); s.run(1000);
    assert(s.pulses.empty() && std::string(s.control.status())=="needs_direction_reference");
    s.summary("unknown_probe_not_authorized_explicit_status"); ++cases;
  }
  {
    Sim s; unknown(s,500,1); s.physical=1; s.run(1000); s.request(-1); s.run(12000);
    assert(s.pulses.size()==2 && s.pos==0 && ok(s));
    s.summary("uncalibrated_known_live_direction_works"); ++cases;
  }
  {
    Sim s; unknown(s,500,1); s.allow_probe=true; s.ignore_presses=true; s.request(1); s.run(10000);
    assert(s.pulses.size()==1 && std::string(s.control.status())=="error_no_motion");
    s.summary("probe_no_feedback_no_retry"); ++cases;
  }
  {
    Sim s; s.prepare(500,1); s.request(1); s.run(500); s.position_known=false; s.run(5000);
    assert(s.pulses.size()==1 && std::string(s.control.status())=="error_encoder_range");
    s.summary("encoder_fault_does_not_enable_probe"); ++cases;
  }
  {
    Sim s; s.prepare(800,1); s.request(-1); s.run(3000); s.physical=1; s.last_physical=1; s.run(6000);
    assert(s.pulses.size()==1); s.summary("obstacle_reversal_not_reclosed"); ++cases;
  }
  {
    Sim s; s.prepare(500,1); s.request(1); s.run(500); s.control=GateController{};
    s.tracker=PositionTracker{}; s.encoder_count=0; s.run(10000);
    assert(s.pulses.size()==1 && !s.control.busy()); s.summary("reboot_no_automatic_resume"); ++cases;
  }
  {
    Sim s; s.prepare(500,1); s.request(1); s.run(500); s.contact_available=false; s.run(9000);
    assert(s.pulses.size()==3 && s.physical==1 && ok(s)); s.summary("network_contact_loss_counting_continues"); ++cases;
  }
  {
    Sim s; s.request(1); for(int i=0;i<40;++i) {s.run(100);s.request(1);} s.run(25000);
    assert(s.pulses.size()==1 && s.pos==1049); s.summary("open_spam_40_no_extra_pulses"); ++cases;
  }
  {
    GateController c; GateObservation o{false,0,0,0,0};
    assert(c.request(1,0xffffff00U,false,true)); assert(c.tick(o,0xffffff00U,false));
    assert(!c.tick(o,0x1300U,false) && !c.busy());
    assert(std::string(c.status())=="error_no_motion"); ++cases;
  }
  std::cout<<"PASS "<<cases<<" v2 cases\n";
}

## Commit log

2026-09-19 Publish sanitized Linear garage controller firmware and documentation
    [garage_gate_controller.yaml]
2026-09-19 Simplify enclosure provenance wording
2026-09-19 Publish V0.27 enclosure STL files and mesh checks
    [garage-v0.27-base.stl, garage-v0.27-lid.stl]
